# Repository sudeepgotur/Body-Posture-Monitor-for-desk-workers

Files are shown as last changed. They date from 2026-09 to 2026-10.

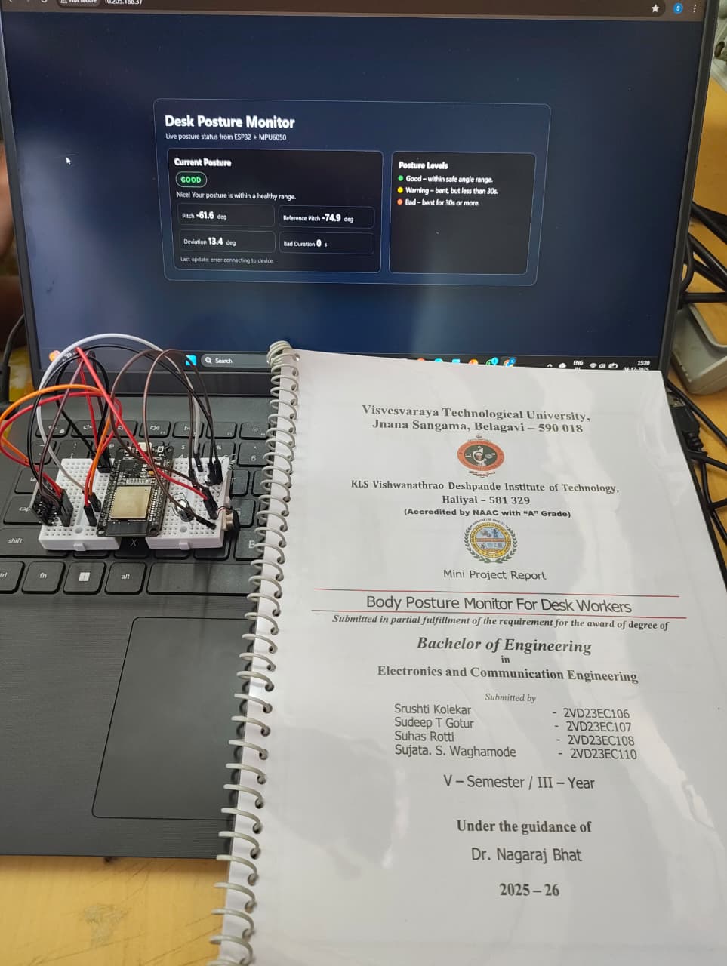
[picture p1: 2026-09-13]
images/final_setup_and_prototype/final_setup.jpeg

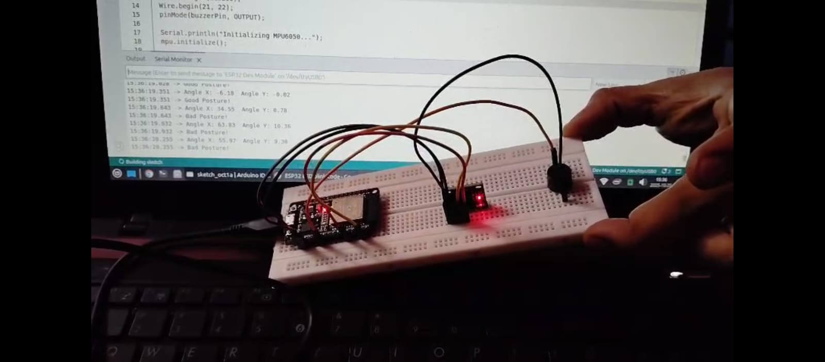
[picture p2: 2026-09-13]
images/final_setup_and_prototype/prototype.jpeg

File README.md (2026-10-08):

# Body Posture Monitor for Desk Workers

An ESP32-based embedded system for real-time posture monitoring and
prolonged bad-posture detection using an MPU6050 IMU sensor, with
vibration-based feedback and an integrated web-based monitoring
interface.

---

## 📌 Overview

The **Body Posture Monitor for Desk Workers** is an embedded system
developed to monitor a user's sitting posture in real time and provide
tactile feedback when an incorrect posture is maintained for a prolonged
period.

The system uses an **MPU6050 inertial measurement unit (IMU)** to obtain
body-orientation information. An **ESP32 microcontroller** processes the
sensor data, performs an initial posture calibration, calculates the
current pitch angle, and compares it with the calibrated reference
posture.

To prevent unnecessary alerts caused by short-term movements, the system
uses a **40-second bad-posture confirmation delay**. If the measured
posture remains outside the allowed range for the complete delay period,
the ESP32 activates a vibration motor to remind the user to correct their
posture.

The ESP32 also hosts a **web server** using its internal Wi-Fi
connectivity. The web interface is stored in the ESP32's **LittleFS
filesystem** and provides real-time posture information through a JSON
API.

A custom PCB was also designed as part of the hardware implementation.

---

## ✨ Features

- Real-time posture monitoring
- MPU6050-based posture sensing
- ESP32-based embedded processing
- Automatic 5-second posture calibration
- Reference posture angle generation
- Pitch-angle calculation
- 15° posture deviation tolerance
- Prolonged bad-posture detection
- 40-second confirmation delay
- Three posture states:
  - `GOOD`
  - `POTENTIALLY_BAD`
  - `BAD`
- Vibration-based tactile feedback
- 3-second vibration alert
- ESP32 Wi-Fi connectivity
- ESP32-hosted asynchronous web server
- LittleFS-based web interface
- Real-time JSON posture API
- Custom PCB design
- Low-cost embedded implementation
- Camera-free posture monitoring

---

# 🏗️ System Architecture

```text
                    ┌─────────────────────┐
                    │       MPU6050       │
                    │     IMU Sensor      │
                    │  Accelerometer/Gyro │
                    └──────────┬──────────┘
                               │
                           I²C / SDA-SCL
                               │
                               ▼
                    ┌─────────────────────┐
                    │        ESP32        │
                    │   Microcontroller   │
                    └──────────┬──────────┘
                               │
                 ┌─────────────┼─────────────┐
                 │             │             │
                 ▼             ▼             ▼
          Posture Logic    Vibrator      Wi-Fi
                 │          Control         │
                 │             │             │
                 ▼             ▼             ▼
          GOOD / BAD      Vibration     Web Server
          Detection          Alert           │
                                             ▼
                                       ┌─────────────┐
                                       │   LittleFS  │
                                       │             │
                                       │ index.html  │
                                       │ script.js   │
                                       │ style.css   │
                                       └──────┬──────┘
                                              │
                                              ▼
                                      Web Monitoring UI
```
---
## ⚙️ Working Principle

The system operates through the following sequence.

### 1. Initialization

When the ESP32 starts, it initializes:
- Serial communication
- I²C communication
- MPU6050
- Vibration motor control GPIO
- LittleFS
- Wi-Fi
- Asynchronous web server
The MPU6050 is connected to the ESP32 using the I²C interface.

### 2. Automatic Posture Calibration

After initialization, the system performs an automatic calibration.
The user is expected to sit in a normal posture for approximately
5 seconds.

During this period, the ESP32 continuously reads the MPU6050 pitch
values and calculates their average.
The resulting average is stored as the reference posture:

```text
              Normal Posture
                    │
                    ▼
             5-second calibration
                    │
                    ▼
              Read pitch values
                    │
                    ▼
              Calculate average
                    │
                    ▼
                 refPitch
```

This reference value is then used for subsequent posture monitoring.

### 3. Pitch Calculation

The ESP32 reads the raw accelerometer values from the MPU6050.

The accelerometer readings are converted into acceleration values and
used to calculate the pitch angle.

The implemented calculation is based on:

`pitch = atan2(Ay, √(Ax² + Az²))`

The resulting angle is expressed in degrees.

### 4. Posture Deviation

After calibration, the current pitch is compared with the calibrated
reference pitch.

The firmware calculates:

`deviation = pitch - refPitch`

The absolute deviation is then compared with the configured posture
tolerance.

The current firmware uses:

`PITCH_TOLERANCE = 15°`

Therefore:

```text
Absolute deviation ≤ 15°
        ↓
     GOOD

Absolute deviation > 15°
        ↓
Potentially incorrect posture
```
---

## 🚦 Posture States

The firmware provides three posture states.

| State | Description |
|---|---|
| `GOOD` | Posture is within the allowed deviation |
| `POTENTIALLY_BAD` | Posture has exceeded the allowed deviation, but the confirmation delay has not expired |
| `BAD` | Incorrect posture has remained beyond the 40-second confirmation period |

The state is provided to the web interface through the `/posture`
endpoint.

---

## ⏱️ Bad-Posture Confirmation

The system does not immediately activate the vibrator when the user's
posture becomes incorrect.

Instead, a timer is started.

```text
                Posture Reading
                      │
                      ▼
              Calculate Deviation
                      │
                      ▼
               Deviation > 15°?
                  │          │
                 NO         YES
                  │          │
                  ▼          ▼
                GOOD    Start Timer
                            │
                            ▼
                      Continue Monitoring
                            │
                            ▼
                      40 Seconds Reached?
                        │            │
                       NO           YES
                        │            │
                        ▼            ▼
               POTENTIALLY_BAD      BAD
                                    │
                                    ▼
                               Vibrator ON
```

If the user returns to the acceptable posture before the 40-second
period expires, the timer is reset.

If the incorrect posture continues for the complete 40 seconds, the
firmware confirms the posture as BAD.

---
                   
## 📳 Vibration Alert

The vibration motor is controlled through a transistor driver connected
to the ESP32.

When bad posture is confirmed:

```text
BAD posture confirmed
        │
        ▼
Vibrator activated
        │
        ▼
Approximately 3 seconds
        │
        ▼
Vibrator switched OFF
```

The current firmware uses a vibration duration of:

`BUZZ_DURATION = 3000 ms`

The vibration provides tactile feedback without requiring a visual or
audible alarm.

---

## 🌐 ESP32 Web Server

One of the important features of this project is that the ESP32
itself acts as the web server.

The firmware uses:

- ESPAsyncWebServer
- AsyncTCP
- WiFi
- ArduinoJson
- LittleFS

The ESP32 connects to a Wi-Fi network and starts an asynchronous web
server on port 80.

The web interface is stored in the ESP32's internal LittleFS
filesystem.

```text
ESP32
 │
 ├── Wi-Fi
 │
 ├── Async Web Server
 │
 └── LittleFS
      │
      ├── index.html
      ├── script.js
      └── style.css
```

---

## 📡 Posture JSON API

The firmware provides a dedicated endpoint:

`/posture`

This endpoint returns posture information in JSON format.

```text
Example structure:
{
    "pitch": 12.5,
    "refPitch": 10.2,
    "deviation": 2.3,
    "badSeconds": 0,
    "status": "GOOD"
}
```

The API provides:

- Current pitch
- Reference pitch
- Pitch deviation
- Duration of the current bad-posture condition
- Current posture status

The web interface can use this information to display the current
posture state and sensor values.

---

## 💾 LittleFS

The project uses LittleFS on the ESP32 to store and serve the web
interface files.

The firmware mounts LittleFS during startup:

```text
LittleFS
   │
   ├── index.html
   ├── script.js
   └── style.css
```

The ESP32 serves these files directly through its web server.

This allows the project to operate as a self-contained embedded web
application without requiring a separate computer or backend server for
the interface.

---

## 💻 Web Interface

The frontend of the project is organized as:

```text
software/
├── index.html
├── script.js
└── style.css
```

### index.html

Defines the structure of the web interface.

### script.js

Handles client-side interaction and communication with the ESP32 posture API.

### style.css

Provides the visual styling of the web interface.

Dashboard screenshots are available in:

```text
images/dashboard/
```

---

## 🔧 Hardware Components

| Component | Purpose |
|---|---|
| **ESP32** | Main microcontroller and processing unit |
| **MPU6050** | Accelerometer and gyroscope for posture sensing |
| **Vibration Motor** | Provides tactile feedback |
| **BC547 Transistor** | Drives the vibration motor |
| **Diode** | Protects the circuit from motor back-EMF |
| **Resistor** | Used in the transistor interface |
| **Capacitor** | Helps reduce power fluctuations and electrical noise |
| **USB Cable** | Programming and power |
| **Custom PCB** | Hardware integration |

---

## 🧩 MPU6050

The MPU6050 is a 6-axis inertial measurement unit containing:

- 3-axis accelerometer
- 3-axis gyroscope

In this project, the sensor is used to obtain body-orientation
information for posture monitoring.

The sensor communicates with the ESP32 using:
I²C

The ESP32 uses the sensor readings to calculate the user's pitch angle
and determine posture deviation from the calibrated reference.

---

## 🔌 Circuit and Vibration Driver

The vibration motor is not driven directly from the ESP32 GPIO.
Instead, a transistor driver stage is used.

```text
             ESP32 GPIO
                  │
                  ▼
             Base Resistor
                  │
                  ▼
              BC547 NPN
                  │
                  ▼
           Vibration Motor
                  │
                  ▼
               GND

```

A protection diode is included to reduce the effects of the motor's
back-EMF.

The circuit diagram is available at:
hardware/circuit_diagram/circuit_diagram.jpeg

---

## 🖥️ Firmware

The main ESP32 firmware is located at:

```text
firmware/
└── ESP_code_for_monitor.ino
```

The firmware handles:

- MPU6050 initialization
- I²C communication
- 5-second calibration
- Pitch calculation
- Posture deviation calculation
- 15° tolerance comparison
- 40-second bad-posture confirmation
- Vibration control
- Wi-Fi connection
- LittleFS
- Web server
- JSON API
- Serial debugging

---

## 🔌 PCB Design

A custom PCB was designed as part of the project to integrate the
required hardware circuitry.

The PCB resources are organized as:

```text
hardware/
└── pcb/
    ├── BOM/
    ├── Final_PCB/
    ├── Gerber_Posture-Monitor-PCB-1_PCB_Posture-Monitor-PCB-1_2026-10-07/
    └── Schematic/
```

Included PCB Resources

- Bill of Materials
- Schematic
- Final PCB design
- Gerber manufacturing files

The PCB files document the hardware design and manufacturing workflow
of the project.

---

## 📷 Project Images

**Final Setup and Prototype**
Images of the physical implementation are available in:

`images/final_setup_and_prototype/`

Contents include:

- Final setup
- Hardware prototype
- Project implementation photographs

**Web Dashboard**
Screenshots of the monitoring interface are available in:

`images/dashboard/`

---

## 📊 Posture Detection Logic

The overall detection process can be summarized as:

```text
                  Start
                    │
                    ▼
              Initialize ESP32
                    │
                    ▼
              Initialize MPU6050
                    │
                    ▼
            5-second Calibration
                    │
                    ▼
              Store refPitch
                    │
                    ▼
              Read MPU6050
                    │
                    ▼
             Calculate Pitch
                    │
                    ▼
          Calculate Deviation
                    │
                    ▼
           Deviation > 15°?
              │           │
             NO          YES
              │           │
              ▼           ▼
            GOOD    POTENTIALLY_BAD
                          │
                          ▼
                      Start Timer
                          │
                          ▼
                    40 Seconds?
                     │        │
                    NO       YES
                     │        │
                     ▼        ▼
                 Continue     BAD
                              │
                              ▼
                         Vibrator ON
                              │
                              ▼
                          ~3 Seconds
                              │
                              ▼
                         Vibrator OFF
                              │
                              ▼
                       Continue Monitoring

```

---

## 🎯 Objectives

The project was developed with the following objectives:

- Design a posture monitoring system for desk workers.
- Measure body orientation using an MPU6050.
- Process sensor data using an ESP32.
- Detect incorrect posture.
- Provide vibration-based feedback.
- Reduce unnecessary alerts caused by temporary movements.
- Implement a delayed alert mechanism.
- Improve awareness of proper sitting posture.

---

## 📈 Project Outcomes

The implemented system demonstrates:

- Real-time posture monitoring.
- MPU6050-based angle measurement.
- Automatic posture calibration.
- Reference-based posture deviation detection.
- 15° posture tolerance.
- 40-second delayed bad-posture confirmation.
- Vibration-based tactile feedback.
- ESP32 Wi-Fi connectivity.
- Embedded web-server functionality.
- LittleFS-based web interface.
- Real-time posture data through a JSON endpoint.
- Custom PCB implementation.

---

## 🛠️ Technologies Used

Hardware

- ESP32
- MPU6050
- Vibration Motor
- BC547 Transistor
- Diode
- Resistors
- Capacitor
- Custom PCB
Embedded Software
- Arduino IDE
- Arduino C/C++
- ESP32 Board Package
- Wire.h
- WiFi.h
- ESPAsyncWebServer
- AsyncTCP
- ArduinoJson
- LittleFS
Communication
- I²C
- Wi-Fi
- HTTP
- JSON
Frontend
- HTML
- CSS
- JavaScript

---

## 📁 Repository Structure

```text
Body-Posture-Monitor-Desk-Workers/
│
├── README.md
├── LICENSE
├── .gitignore
│
├── docs/
│
├── firmware/
│   └── ESP_code_for_monitor.ino
│
├── hardware/
│   ├── circuit_diagram/
│   │   └── circuit_diagram.jpeg
│   │
│   └── pcb/
│       ├── BOM/
│       ├── Final_PCB/
│       ├── Gerber_Posture-Monitor-PCB-1_PCB_Posture-Monitor-PCB-1_2026-10-07/
│       └── Schematic/
│
├── images/
│   ├── dashboard/
│   │   ├── Posture_image1.jpeg
│   │   ├── Posture_image2.jpeg
│   │   ├── Posture_image3.jpeg
│   │   └── Posture_image4.jpeg
│   │
│   └── final_setup_and_prototype/
│       ├── final_setup.jpeg
│       ├── final_setup2.jpeg
│       └── prototype.jpeg
│
└── software/
    ├── index.html
    ├── script.js
    └── style.css

```

---

# 📚 Documentation

The `docs/` directory contains the project's detailed documentation
and presentation materials.

### Project Report

The complete project report contains detailed information about the
project, including the problem statement, objectives, methodology,
hardware and software implementation, results, and project outcomes.

### Project Presentation

The project presentation provides a concise overview of the system,
its architecture, implementation, and results.

```text
docs/
├── Body Posture Monitor For Desk Workers (4) [1].pptx
└── Project_report_final(BPM)[1](AutoRecovered)[1].pdf
```

---

## 🏫 Project Information

**Project Title**: Body Posture Monitor for Desk Workers
**Project Type**: Mini Project
**Department**: Electronics and Communication Engineering
**Institution**: KLS Vishwanrao Deshpande Institute of Technology, Haliyal
**University**: Visvesvaraya Technological University (VTU)
**Academic Year**: 2025–2026
**Guide**: Dr. Nagaraj Bhat

---

## 👥 Team Members

- **Srushti Kolekar** — 2VD23EC106
- **Sudeep T. Gotur** — 2VD23EC107
- **Suhas Rotti** — 2VD23EC108
- **Sujata S. Waghamode** — 2VD23EC110

---

## 👨‍💻 My Contribution

My primary contribution to the project focused on the hardware and
embedded-system implementation.

Hardware
- ESP32 and MPU6050 interfacing
- Sensor integration
- Circuit implementation
- Hardware assembly
- Testing and debugging
- Completed the PCB development

Embedded System
- ESP32 firmware development
- MPU6050 sensor data acquisition
- Posture calibration
- Posture-angle calculation
- Posture detection logic
- Bad-posture timing mechanism
- Vibration-alert control

Web Interface
- LittleFS integration
- Posture JSON API
- Integration of the embedded system with the web interface

---

## 📜 License

This project is released under the MIT License.
See the LICENSE file for details.

---

## 👤 Author

Sudeep T. Gotur
Bachelor of Engineering
Electronics and Communication Engineering
KLS Vishwanrao Deshpande Institute of Technology, Haliyal

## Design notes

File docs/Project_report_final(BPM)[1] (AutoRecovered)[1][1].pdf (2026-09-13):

Visvesvaraya Technological University,

# Jnana Sangama, Belagavi – 590 018

## Under the guidance of

## Dr. Nagaraj Bhat

2025 – 26

KLS Vishwanathrao Deshpande Institute of Technology,

## Haliyal – 581 329

(Accredited by NAAC with “A” Grade)

## Mini Project Report

# Body Posture Monitor For Desk Workers

Submitted in partial fulfillment of the requirement for the award of degree of

# Bachelor of Engineering

in

## Electronics and Communication Engineering

Submitted by
Srushti Kolekar | - 2VD23EC106
Sudeep T Gotur | - 2VD23EC107
Suhas Rotti | - 2VD23EC108
Sujata. S. Waghamode | - 2VD23EC110

## V – Semester / III – Year

Visvesvaraya Technological University,

# Jnana Sangama, Belagavi – 590 018

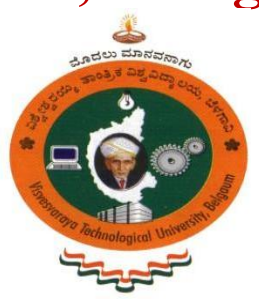
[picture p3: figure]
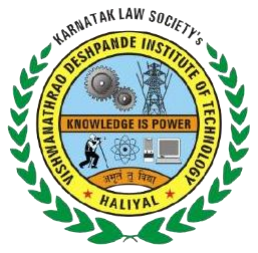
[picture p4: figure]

### Under the guidance of

## Dr. Nagaraj Bhat

2025 – 26

KLS Vishwanathrao Deshpande Institute of Technology,

## Haliyal – 581 329

(Accredited by NAAC with “A” Grade)

## Department of Electronics and Communication Engineering

## Mini Project Report

# Body Posture Monitor For Desk workers

Submitted by
Srushti Kolekar | - 2VD23EC106
Sudeep T Gotur | - 2VD23EC107
Suhas Rotti | - 2VD23EC108
Sujata S. Waghamode | - 2VD23EC110

## V – Semester / III – Year

Visvesvaraya Technological University,

## Jnana Sangama, Belagavi – 590 018

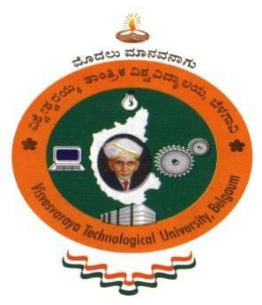
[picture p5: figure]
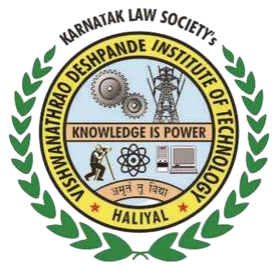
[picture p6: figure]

KLS Vishwanathrao Deshpande Institute of Technology,

## Haliyal – 581 329

(Accredited by NAAC with “A” Grade)

## Department of Electronics and Communication Engineering

## CERTIFICATE

Certified that the Mini Project Work entitled “ Body Posture Monitor for Desk Workes” carried out by

Srushti Kolekar | - 2VD23EC106
Sudeep T Gotur | - 2VD23EC107
Suhas Rotti | - 2VD23EC108

Sujata S. Waghamode - 2VD23EC110

are Bonafide Students of KLS VDIT, Haliyal, in partial fulfillment for the award of Bachelor of Engineering in Electronics and Communication Engineering, of the Visvesvaraya Technological University, Belagavi during the Year 2025-2026. It is certified that all corrections / suggestions indicated for Internal Assessment have been incorporated in the Report deposited in the Departmental Library. The Mini Project report has been approved as it satisfies the academic requirements in respect of Mini Project Work prescribed for the said Degree.

GUIDE
(Dr. Nagaraj Bhat)

HOD
(Dr. Nagaraj Bhat)

PRINCIPAL
(Dr. V. A. Kulkarni)
Name of the Examiners | Signature with Date

1.

2.

============================================================================================== ================================================================

Body Posture monitor For Desk Workers
============================================================================

=============================================================================

## TABLE OF CONTENTS

Sl. No | Contents | Page No.
1 | Introduction | 1
2 | Literature Survey | 2
3 | Methodology | 4
4 | Outcomes | 10
5 | Advantages | 13
6 | Applications | 15
7 | Conclusion | 16
8 | References | 17

## LIST OF FIGURES

Sl. No | List of Figures | Page No.
1 | Block Diagram of Posture Corrector | 6
2 | Flowchart Of Posture Correction System | 8
3 | Posture is Good | 12
4 | Posture Warning | 12
5 | Posture is Bad | 12

Dept. of E&C, KLS VDIT, Haliyal | 1
Page No.

## CHAPTER 1:

## INTRODUCTION

## 1.1 Introduction

In today’s digital era, many people spend long hours sitting at desks, often in front of computers. Poor

sitting or standing posture over prolonged periods can lead to back pain, spinal misalignment, and other

health issues. Maintaining correct posture is essential for the overall health and productivity of desk

workers, students, and professionals. With the advancement of sensor-based technology and affordable

microcontrollers, it is now possible to develop compact devices that can monitor posture and alert users in

real time.

## 1.2 Motivation

Observations show that most individuals working for extended hours at desks are unaware of their body

posture. Continuous bending or slouching causes strain on the neck and spine. This motivated the

development of a small, wearable, and cost-effective device that can detect improper posture and remind

users to correct it, thereby improving health and comfort

## 1.3 Objectives

1.To design a wearable system for detecting incorrect sitting posture.

2.To Interface Flex sensor with ESP32 using MPU6050 for quaternion-based tracking.

3.To generate alerts using vibration motor when posture deviates beyond threshold.

4.To ensure portability by integrating the system into a light weight jacket.

5.To promote better erogonomics for desk workers and reduce health risks.

## 1.4 Scope of the Project

The proposed system is a portable, low-cost posture monitoring device using an ESP32 microcontroller

and an MPU6050 sensor. It can be used by anyone who spends long hours sitting or standing in a fixed

position. The project also provides a base for future enhancement, such as adding IoT features for mobile

notifications, data logging, and posture-tracking analytics.

## CHAPTER 2:

## LITERATURE SURVEY

1. UWB-Posture Guard: A Privacy-Preserving RF Sensing System for Continuous Ergonomic Sitting

Posture Monitoring

Authors: Haotang Li et all

Explanation:

- Contactless Monitoring: Uses ultra-wideband (UWB) RF signals to sense posture without cameras

or wearables, ensuring strong privacy.

- Temporal Classification: Introduces a gradient-boosted decision-tree model (PoseGBDT) for

analyzing continuous posture sequences.

- High Accuracy: Achieves ~99% accuracy across 19 sitting postures, robust against clothing,

devices, and environmental changes.

- Real-World Usability: Designed for continuous, long-term ergonomic monitoring in offices while

minimizing invasiveness.

### 2. Sitting Posture Recognition and Feedback: A Literature Review

Authors: Christian Krauter et al.

Explanation:

- Comprehensive Survey: Reviews 223 papers related to sitting posture detection and feedback

mechanisms.

- Common Technologies: Finds that pressure sensors and visual feedback systems are the dominant

sensing and feedback methods.

- Design Trade-offs Identified: Highlights challenges such as privacy, accuracy, cost, and user comfort

across different approaches.

- Gap in Long-Term Studies: Notes lack of consistent evaluation methods and calls for long-term, real-

world posture studies.

### 3. Sensor-Based Wearable Systems for Monitoring Human Motion and Posture: A Review

Authors: Xinxin Huang et al.

Explanation:

- Wearable Focus: Provides a wide review of wearable sensors (IMUs, accelerometers, gyros, flexible

sensors) used for motion/posture monitoring.

- Sensor Placement Analysis: Discusses optimal placement (waist, trunk, limbs) and how placement

affects accuracy and comfort.

- System Design Discussion: Covers complete pipeline: sensing, transmission, processing, and real-time

monitoring challenges.

- Future Challenges: Identifies accuracy, durability of flexible sensors, and data privacy as critical areas

for improvement.

4. A Smart System for Sitting Posture Detection Based on Force Sensors and Mobile Application

Authors: Slavomir Matuska et al.

Explanation:

- Pressure-Based System: Uses 6 force sensors embedded in a chair to detect multiple sitting postures.
- IoT Architecture: Employs Arduino/NodeMCU to collect data and send posture information to a

mobile app.

- Real-Time Feedback: Mobile app provides posture warnings and tracks long-term sitting behavior.
- Practical Implementation: Designed for office use and demonstrates a low-cost, deployable smart-chair

solution.

### 5. Human Posture Detection Method Based on Wearable Devices

Authors: Xiaoou Li, Yangang Li, Yuanming Wu, Jiahui Xu, Zhitao Xiao

Explanation:

- Multi-Sensor Fusion: Combines upper-limb sEMG, triaxial acceleration, and plantar pressure

sensors for posture and gait recognition.

- Feature Engineering: Extracts statistical and wavelet features from EMG and IMU data for robust

classification.

- Machine Learning: Uses a GA-optimized SVM classifier to improve detection accuracy.
- Strong Performance: Achieves ~90% accuracy for both virtual motion control and gait recogniti

## CHAPTER 3:

## METHODOLOGY

This chapter explains the overall design, components used, system architecture, and working principle of

the Body Posture Monitoring System for Desk Workers. The system combines sensor-based angle

detection, microcontroller processing, and delayed feedback to help users maintain proper sitting posture.

## 3.1 Overview

The proposed system is designed to continuously monitor the posture of a desk worker using an MPU6050

accelerometer-gyroscope sensor. The sensor measures the tilt angle of the upper body. The ESP32

microcontroller processes these readings and compares them with a calibrated baseline posture. If a user

bends or leans forward beyond a certain angle and maintains this incorrect posture for more than 40 seconds,

the system activates a vibrater to alert the user.

The system is:

- Low cost
- Non-intrusive (no camera, no wearable)
- Simple to use
- Real-time
- Highly suitable for desk workers and students

To prevent false alerts when the user bends briefly to pick up an object or reach for something, a time delay

mechanism is added.

## 3.2 Hardware Components Used

- ESP32 Microcontroller

Acts as the main controller.

Performs sensor reading, data processing, and vibration control.

- MPU6050 (Accelerometer + Gyroscope)

Mounted on the upper limb/back.

Measures body tilt to identify slouching or leaning forward.

- Flex Sensor

Placed on the lower limb.

Detects bending of the knee or excessive forward leaning.

- Vibration Motor (Coin Type)

Provides haptic feedback when the posture is incorrect for a prolonged period.

- BEC548 Transistor

Used as a driver to control the vibration motor safely.

- 1N4148 / 1N4007 Diode

Protects the circuit from motor back-EMF.

- 100 µF Capacitor

Smoothens motor power fluctuations and reduces electrical noise.

- Resistors

1 kΩ for transistor base.

## 3.3 Software Components Used

1. Arduino IDE
- Used for writing, compiling, and uploading the ESP32 program
2. ESP32 Board Package
- Required to program ESP32 in Arduino IDE
- Provides GPIO definitions and bootloader support
3. Wire.h Library
- Enables I2C communication between ESP32 and MPU6050
4. Core Embedded C/C++ Code
- Implements:
- Sensor calibration
- Complementary filtering
- Angle computation

## 3.4 Block diagram

The block diagram represents the overall functioning of the “Body Posture for Desk Workers” system. The

MPU6050 and flex sensor act as the primary input units that continuously monitor the user’s upper-body

tilt and lower-limb bending. These sensors send real-time analog and digital data to the ESP32

microcontroller, which serves as the central processing unit of the system. Inside the ESP32, the posture

data is filtered, processed, and compared with predefined thresholds to determine whether the user is

maintaining a correct or incorrect sitting posture. A timing logic is also implemented so that incorrect

posture must be sustained for more than 40 seconds before triggering feedback. Once the ESP32 detects

prolonged bad posture, it activates the vibration motor through a transistor driver circuit. This haptic

feedback alerts the user to correct their posture, making the system an effective and non-intrusive posture

correction tool.

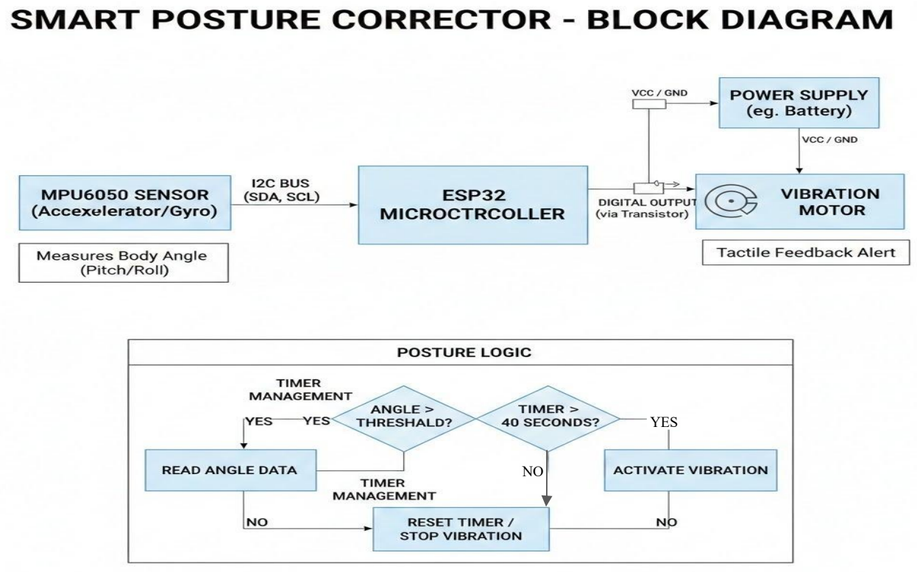
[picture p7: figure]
YES

Fig: 3.1 Block Diagram of Posture Corrector

## 3.5 Flowchart

The flowchart describes the step-by-step operational logic of the posture monitoring system. It outlines

how the system reads sensor data, processes posture, and triggers an alert only when necessary.

1. Start System

The ESP32 initializes all hardware components, including I2C communication and the MPU6050

sensor.

The system also performs a calibration phase where the baseline posture angle is recorded.

2. Read MPU6050 Values

The ESP32 continuously reads accelerometer and gyroscope data from the MPU6050. These raw values

represent the user’s real-time movement and orientation.

3. Calculate Angle

Using the complementary filter technique, the ESP32 calculates a stable pitch angle of the user’s upper

body. This angle indicates how far the user is leaning forward or backward.

4. Compare Angle with Baseline

The calculated angle is compared with the calibrated baseline angle.

- If the angle difference is below the threshold, the posture is considered correct.
- If it exceeds the threshold, the posture is considered bad.
5. Posture OK (Good Posture Path)

If the posture is correct:

- The system resets the timer.
- The vibrator remains OFF.
- The system continues monitoring without any interruption

6.Bad Posture Detected (Angle > Threshold)

When the system detects bad posture:

- It does NOT activate the vibrator immediately.
- Instead, it starts or continues a timer to track how long the user remains in bad posture.

7.Check Timer (40 Seconds)

If the user stays in incorrect posture for less than 40 seconds

- No vibrator is activated.
- This prevents false alerts caused by temporary actions like picking up a pen or leaning briefly.

If the timer reaches or exceeds 40 seconds, the system proceeds to the next step.

8.Turn Vibrator ON

If bad posture persists beyond 40 seconds, the ESP32 activates the vibrator to alert the user.

The vibrator remains ON until the user corrects their posture and the angle returns within the threshold

limits.

9.Continuous Monitoring

The system loops back to continuously read data and analyze posture, ensuring real-time monitoring

throughout the user’s sitting period.

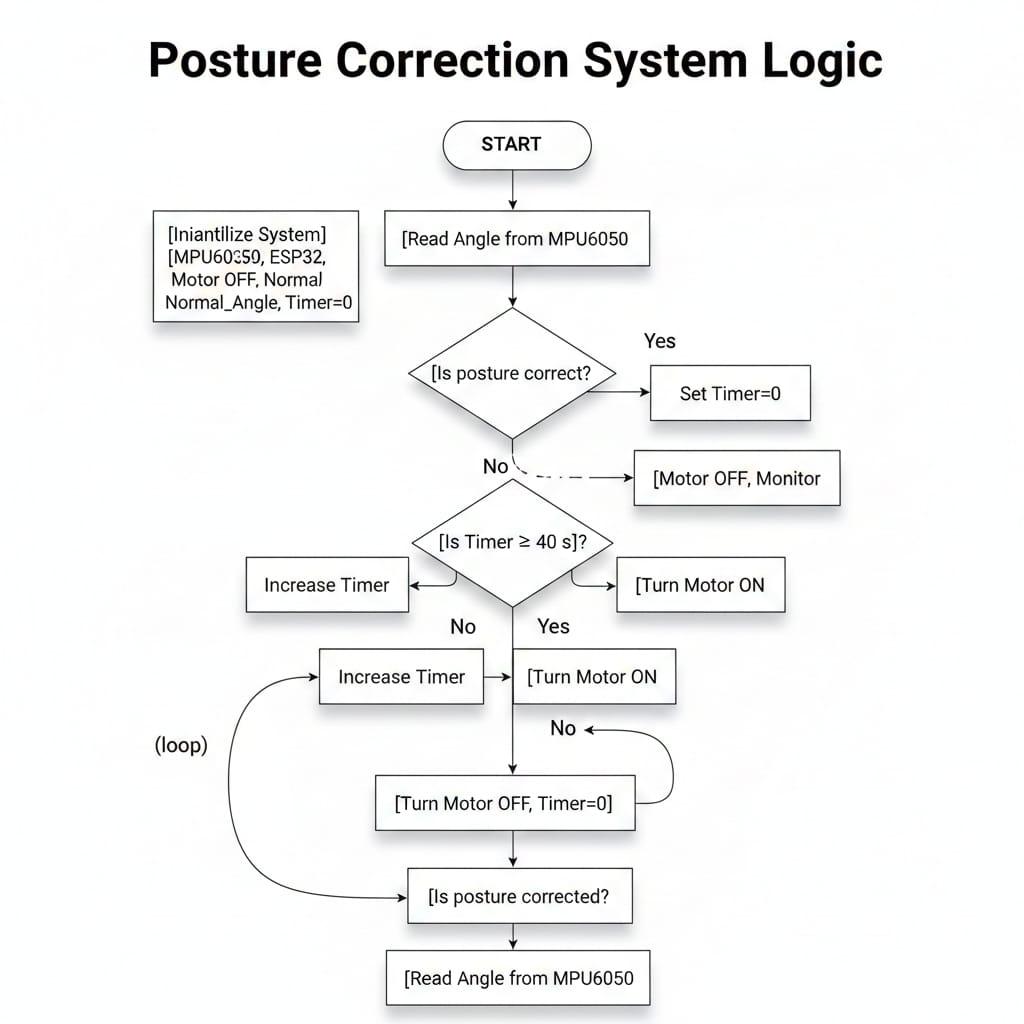
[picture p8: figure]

Fig:3.2 Flowchart of Posture Correction System

## 3.6 Working of system

Step 1: Initialization
- ESP32 boots and initializes I2C communication.
- MPU6050 is calibrated for 5 seconds while the user sits in a normal posture.
- The baseline pitch angle is stored.
Step 2: Reading Sensor Data
- MPU6050 sends accelerometer and gyroscope values continuously.
- ESP32 reads this data at regular intervals.
Step 3: Angle Calculation
- Using both accelerometer and gyroscope, a complementary filter computes a stable pitch angle.
- This angle represents the user’s upper-body tilt.
Step 4: Posture Classification
- ESP32 compares the real-time angle with the baseline angle.
- If the angle difference is within the threshold, posture is considered normal.
Step 5: Delay Logic for False-Alert Prevention
- If bad posture is detected, a timer starts.
- If user corrects posture before 40 seconds, the timer resets (no vibration).
Step 6: Vibrator Alert
- If bad posture continues beyond 40 seconds, ESP32 activates the vibrator.
- The vibrator remains ON until the user returns to a normal posture.
Step 7: Continuous Monitoring
- The system runs 24/7 as long as it is powered.
- Helps users maintain correct posture through immediate feedback.

## CHAPTER 4:

## OUTCOME

The Body Posture Monitoring System for Desk Workers is designed to detect incorrect sitting posture and

provide timely feedback to the user. After implementation and testing, the following outcomes were

achieved:

- Accurate Posture Angle Measurement

The system should correctly detect upper-body tilt using the MPU6050 sensor and measure the posture

angle in real time.

- Reliable Bad Posture Detection

The system is expected to classify posture as “good” or “bad” based on a predefined angle threshold.

- Delay-Based Alert Mechanism

The system should only trigger an alert if the user maintains incorrect posture continuously for more

than 40 seconds.

- Instant User Feedback

When prolonged bad posture is detected, the vibrator should activate immediately to alert the

user.

- User-Friendly Operation

The system should run automatically without requiring complex setup, calibration, or wearable

devices.

## 4.2 Achieved Outcomes

1. Stable and Real-Time Angle Monitoring

The MPU6050 successfully captured continuous accelerometer and gyroscope readings.

The complementary filter produced stable pitch-angle values with minimal noise.

2. Correct Posture Classification

The system correctly identified good posture when the angle difference remained below the set

threshold (e.g., 25°).

Incorrect posture was detected consistently when the user leaned forward beyond the threshold.

3. Accurate 40-Second Delay Implementation

The timer logic worked as intended:

a. No vibrator during short accidental movements.
b. Alert triggered only when the user stayed in bad posture for ≥ 40 seconds.
4. Effective vibrator Feedback

The vibrator activated immediately after the delay time was crossed.

It switched OFF as soon as the user corrected their posture.

5. Simple, Low-Cost, and Non-Intrusive System

The whole system worked without wearables, cameras, or bulky hardware.

It required only ESP32, MPU6050, and a vibrator.

## 4.3 Measurable System Performance

### 1. Angle Detection Accuracy

- The MPU6050 provided consistent angle readings with good stability.
- The complementary filter ensured smooth and accurate posture angle calculation.

### 2. False Alarm Prevention

- Short-duration bending (< 40 seconds) did not trigger the vibrator.
- This confirms the delay mechanism works effectively.

### 3. Responsiveness

- vibrator activation occurred within 1–2 seconds after the 40-second timer completed.
- System responded instantly when posture was corrected.

### 4. Continuous Operation

- The system remained stable during long monitoring sessions (1–2 hours).

## 4.4 Benefits of the Developed System

1. Improves Ergonomic Awareness

Users become conscious of their sitting posture during work or study.

2. Reduces Risk of Back and Neck Pain

Immediate feedback helps prevent prolonged slouching, protecting spinal health.

3. Low-Cost and Easily Reproducible

Uses inexpensive components suitable for student and office applications.

4. Non-Intrusive and Privacy-Friendly

No camera, no wearable devices, no personal data collection.

5. Suitable for Long-Duration Use

Ideal for desk workers, students, programmers, and office employees.

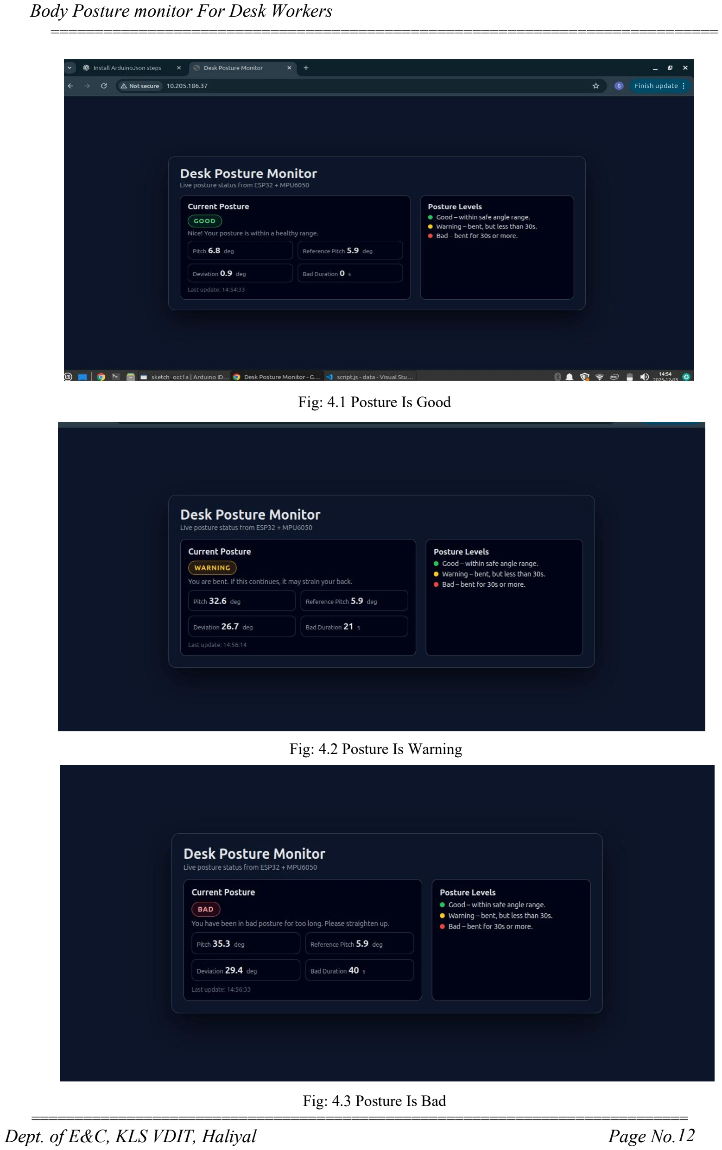
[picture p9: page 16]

Fig: 4.1 Posture Is Good

Fig: 4.2 Posture Is Warning

Fig: 4.3 Posture Is Bad

## CHAPTER 5:

## ADVANTAGES

The Body Posture Monitoring System for Desk Workers offers several practical and technical

advantages that make it an effective, reliable, and user-friendly solution for posture correction. The key

advantages are outlined below:

### 1. Low-Cost and Easily Implementable

The system uses inexpensive and readily available components such as the ESP32, MPU6050, and a

simple vibrator. This makes it affordable for students, offices, and personal use without requiring

specialized hardware or complex installations.

### 2. Real-Time and Continuous Monitoring

The posture of the user is monitored continuously in real time. This ensures that even small posture

deviations or prolonged slouching are detected immediately, allowing users to maintain correct posture

during extended working hours.

### 3. High Accuracy Using Sensor

The MPU6050 provides reliable accelerometer and gyroscope readings. Through complementary

filtering, the system achieves stable and accurate posture angle calculations, making detection precise

and trustworthy.

### 4. Prevents False Alerts

A major advantage of this system is its 40-second delay mechanism. The vibrator triggers only when

the user maintains a bad posture for an extended duration. This prevents unnecessary alerts when the

user bends temporarily to adjust their seating or pick something up.

### 5. Simple and User-Friendly Operation

The system requires no calibration beyond initial setup and does not demand any technical knowledge

from the user. Once powered ON, it works automatically in the background without disturbing normal

activities.

### 6. Privacy-Friendly Solution

Unlike camera-based posture monitoring systems, this design uses only motion data. It does not record

any video or image, making it completely privacy-safe for homes, offices, libraries, and shared

environments.

### 7. Non-Intrusive and Comfortable

The system does not require the user to wear any device or attach sensors to the body. It can be placed

on the desk or integrated into the chair, providing full comfort and ease of use.

### 8. Portable and Compact Design

Using compact components like ESP32 and MPU6050, the system is lightweight and portable. It can be

used across multiple locations such as study rooms, classrooms, and workplace cabins.

### 9. Promotes Healthy Sitting Habits

By providing timely alerts, the system helps users correct their posture regularly. Over time, this

encourages better spinal alignment, reduces back/neck pain, and improves long-term health.

### 10. Expandable and Upgradable

The system can be easily upgraded with additional features such as:

- Mobile notifications via Wi-Fi
- Data logging
- Habit tracking
- AI-based analytics

The ESP32’s capabilities make future enhancements simple to implement

## CHAPTER 6:

## APPLICATIONS

The Body Posture Monitoring System for Desk Workers can be applied in various environments where

people sit for long hours. Its simple design, low cost, and non-intrusive operation make it useful for

multiple practical applications.

### 1. Office Workspaces

Employees often spend long periods sitting at desks, leading to poor posture habits. This system can be

used in corporate offices to help workers maintain an ergonomic sitting posture and prevent back and neck

pain.

### 2. Home Study Rooms

Students studying at home frequently develop unhealthy posture while reading, writing, or using

computers. The device can assist in developing and maintaining correct sitting habits to avoid long-term

spinal issues.

### 3. Schools and Educational Institutions

Libraries, computer labs, and classrooms can benefit from this system. It helps students maintain posture

while performing academic tasks, improving concentration and long-term health.

### 4. IT Companies and Coding Environments

Programmers and developers typically sit for extended hours. This system provides constant posture

monitoring to prevent slouching, spinalstrain, and fatigue—common issues in the IT industry.

### 5. Co-Working Spaces

Shared office environments can adopt this device to promote user wellness and encourage good sitting

posture among individuals working independently.

### 6. Medical and Physiotherapy Centers

The system can assist physiotherapists in monitoring posture improvement in patients undergoing therapy

for back or neck pain. It can also be used in rehabilitation exercises where posture tracking is important.

### 7. Remote Work and Work-From-Home Setups

Many individuals working from home lack ergonomic furniture. This posture monitoring system helps

them maintain healthy posture during long work sessions in informal environments.

## CONCLUSION

The “Body Posture for Desk Workers” system successfully demonstrates a practical and effective solution for

monitoring and correcting poor sitting posture using low-cost hardware components. By integrating an

MPU6050 sensor on the upper limb and a flex sensor on the lower limb, the system is able to continuously

measure body tilt and bending angles with good accuracy. The ESP32 microcontroller plays a central role in

processing real-time sensor data, applying threshold conditions, and determining whether the user is sitting

correctly or not. The inclusion of a 40-second delay mechanism ensures that the system avoids false triggers

caused by short-term movements, such as reaching for objects or adjusting the seat position. This greatly

improves the reliability and usability of the design in real working environments.

The vibration motor provides a simple yet effective feedback method that immediately alerts the user to correct

their posture without disturbing others. Throughout testing, the system showed stable performance, quick

response, and minimal false positives, making it suitable for office workers, students, and individuals who spend

long hours at a desk. The project meets its primary objectives of creating a compact, affordable, and privacy-

preserving posture correction device. Overall, the system promotes healthier sitting habits, reduces the risk of

posture-related discomfort, and demonstrates how embedded systems can be applied to improve daily

ergonomic awareness.

In addition to achieving its technical objectives, this mini-project highlights the potential of combining simple

wearable sensors with intelligent decision logic to address real-world ergonomic problems. The system

demonstrates that posture monitoring does not require complex or expensive equipment; instead, effective

results can be achieved through thoughtful sensor placement, smart timing mechanisms, and user-friendly

feedback methods. The project also reinforces the growing importance of health-focused embedded systems,

especially for individuals who spend extended hours sitting for work or study. By encouraging better posture

habits through timely feedback, the system contributes to long-term health benefits and improved productivity.

This work can further serve as a foundation for developing more advanced posture monitoring solutions with

expanded sensing capabilities, data logging, analytics, or integration with mobile applications.

## REFERENCES

1. UWB-Posture Guard: A Privacy-Preserving RF Sensing System for Continuous Ergonomic Sitting

Posture Monitoring

Authors: Haotang Li, Zhenyu Qi, Sen He, Kebin Peng, Sheng Tan, Yili Ren, Tomas Cerny, Jiyue Zhao,

Zi Wang.(2025)

2. Sitting Posture Recognition and Feedback: A Literature Review

Authors: Christian Krauter, Katrin Angerbauer, Aimée Sousa Calepso, Alexander Achberger, Sven

Mayer, Michael Sedlmair.(2024)

3. Sensor-Based Wearable Systems for Monitoring Human Motion and Posture: A Review

Authors: Xinxin Huang, Yunan Xue, Shuyun Ren, Fei Wang. (2024)

4. A Smart System for Sitting Posture Detection Based on Force Sensors and Mobile Application

Authors: Slavomir Matuska, Martin Paralic, Robert Hudec. (2022)

5. Human Posture Detection Method Based on Wearable Devices

Authors: Xiaoou Li, Yangang Li, Yuanming Wu, Jiahui Xu, Zhitao Xiao (2021)

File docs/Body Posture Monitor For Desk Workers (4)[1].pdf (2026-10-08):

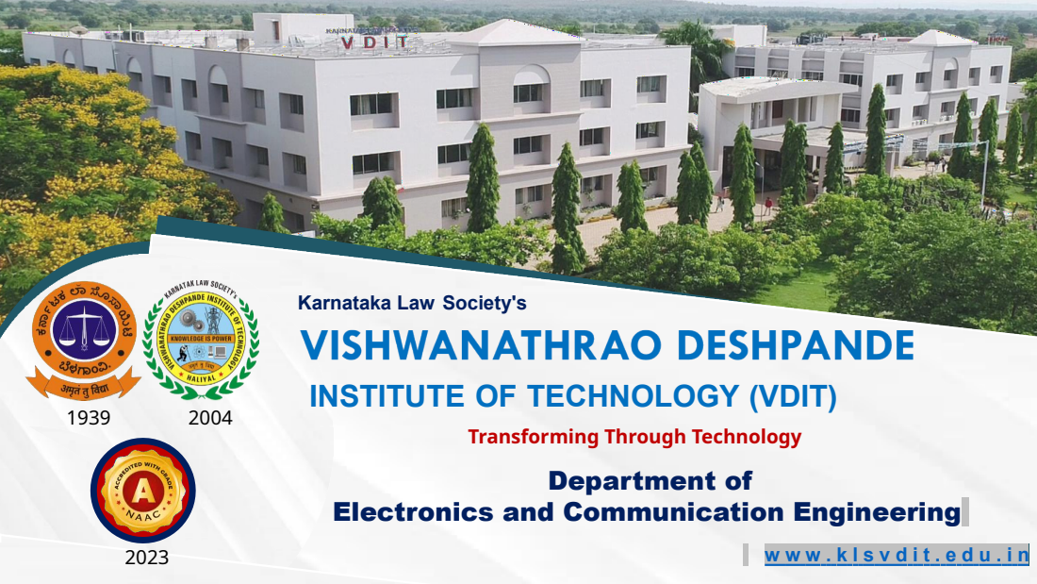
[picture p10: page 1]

Karnataka Law Society's

INSTITUTE OF TECHNOLOGY (VDIT)

Transforming Through Technology
Department of

Electronics and Communication Engineering

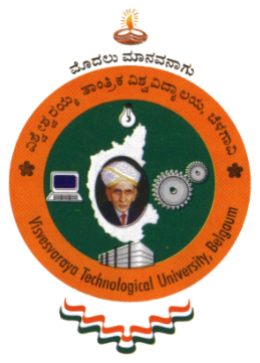
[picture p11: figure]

A Presentation entitled
Body Posture Monitor For Desk Workers

Presented by

Under the Guidance of

Dr. Nagaraj. Bhat

Department of E&CE

(Academic Year 2024-25)

Visvesvaraya Technological University, Jnana Sangama,

### Belagavi – 590 018

KLS Vishwanathrao Deshpande Institute of Technology,

## Haliyal – 581 329

(Accredited by NAAC with “A” Grade)

Srushti Kolekar | 2VD23EC106
Sudeep T. Gotur | 2VD23EC107
Suhas Rotti | 2VD23EC108
Sujata S. Waghamode | 2VD23EC110

09/10/2026 | 3

# PRESENTATION OUTLINE

Ø Motivation
Ø Introduction
Ø Literature Survey
Ø Objectives
Ø Block Diagram
Ø Circuit Diagram
Ø Working
Ø Outcomes
Ø Advantages
Ø Applications
Ø References
Ø Acknowledgement

Body Posture Monitor For Desk Workers

# MOTIVATION

ØMany desk workers suffer from back pain and neck pain

ØPeople unknowingly sit in the wrong posture for long hours

ØNo real-time alert system to correct posture

ØMedical treatment is costly and time-consuming

ØPrevention is better than a cure

ØSimple technology can improve daily life

ØOur goal is to use sensors to improve human health

ØThis project brings technology and health together

# INTRODUCTION

### ØBody posture is the position in which we sit or stand

### ØCorrect posture keeps the spine healthy

### ØDesk workers sit for long hours daily

### ØWrong sitting posture causes: ( Back pain, Neck pain, Shoulder strain)

### ØMost people do not realise when their posture is wrong

### ØTechnology can help by detecting posture automatically

### ØOur project monitors posture and gives feedback using vibration alerts

# LITERATURE SURVEY

SL. N O | Paper Title | Author Names | Proposed Work | Publishe d Year
1 | UWB-PostureGuard: A Privacy-Preserving RF Sensing System for Continuous Ergonomic Sitting Posture Monitoring | Haotang Li, Zhenyu Qi, Sen He, Kebin Peng, Sheng Tan, Yili Ren, Tomas Cerny, Jiyue Zhao, Zi Wang | Proposes a contactless, UWB (ultra-wideband) RF sensing system that continuously monitors sitting posture with 99.11% accuracy. It preserves user privacy (no camera/wearables) and is robust to variations like clothing, furniture, and environment. | 2025
2 | Sitting Posture Recognition and Feedback: A Literature Review | Christian Krauter, Katrin Angerbauer, Aimée Sousa Calepso, Alexander Achberger, Sven Mayer, Michael Sedlmair | Comprehensive literature review (N=223) across engineering, electronics, medical sciences; highlights use of pressure-sensing hardware and visual feedback; discusses factors such as environment, cost, privacy, portability, accuracy, user capability and long-term effects | 2024
3 | Sensor-Based Wearable Systems for Monitoring Human Motion and Posture: A Review

Xinxin Huang, Yunan Xue,
Shuyun Ren, Fei Wang

Systematic review of wearable posture-monitoring systems; analyses sensor types (IMU, flex, pressure), placement strategies, system design aspects, and emphasises future needs like accuracy, data security, comfort, and durability.

2024

09/10/2026 | Body Posture Monitor For Desk Workers | 6

09/10/2026 | Body Posture Monitor For Desk Workers | 7
SL.N O | PAPER TITLE | AUTHOR NAMES | PROPOSED WORK | PUBLISHE D YEAR
4. A Smart System for Sitting | Posture Detection Based on Force Sensors and Mobile Application | Slavomir Matuska, Martin Paralic, Robert Hudec | Presents a smart chair with six flexible force sensors connected to an Arduino-based IoT node; detects incorrect sitting positions and sends feedback to a mobile app, with posture data stored in a private cloud and visualized | 2022
5. | Human Posture Detection Method Based on Wearable Devices | Xiaoou Li Yangang Li Yuanming Wu Jiahui Xu Zhitao Xiao | Proposes a multimodal wearable posture detection method using upper-limb sEMG, lower-limb inertial and plantar pressure sensors; features are extracted via wavelet transforms and classified using optimized | 2021

via mobile UI.

SVM with ~90% accuracy.

# LITERATURE SURVEY

# OBJECTIVES

ØTo design a posture monitoring system for desk workers. ØTo measure body angle using the MPU6050 sensor.
ØTo process sensor data using ESP32.
ØTo detect wrong posture accurately.
ØTo alert the user using vibration feedback.
ØTo avoid false alerts during temporary movements.
ØTo implement a 40-second delay before triggering vibration. ØTo improve health and working comfort.

# COMPONENTS

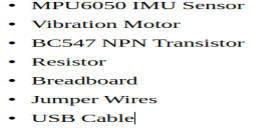
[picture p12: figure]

# BLOCK DIAGRAM

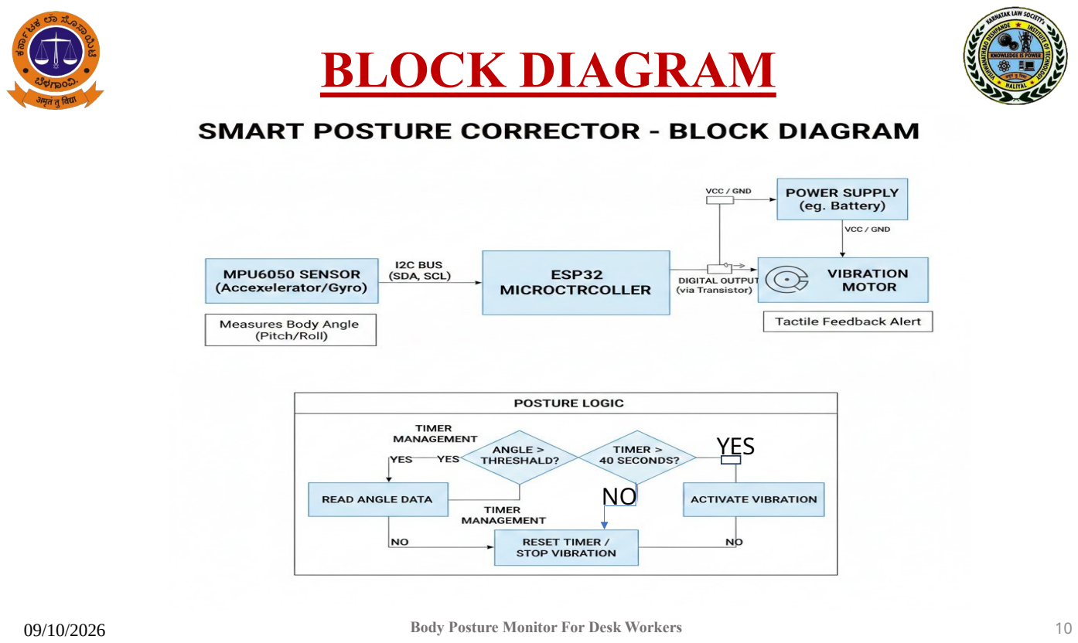
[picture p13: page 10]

YES
NO

# CIRCUIT DIAGRAM

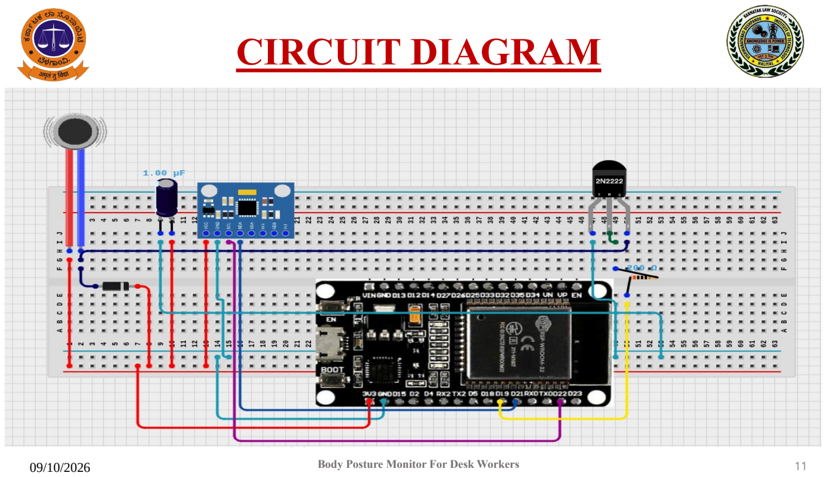
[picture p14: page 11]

Fig.1 : Block Diagram of Body Posture Monitor For Desk Workers

# WORKING

ØThe MPU6050 sensor continuously measures body angle. ØESP32 reads angle data from MPU6050.
ØThe angle is compared with a preset normal posture value. ØIf posture is correct → System continues monitoring.
ØIf posture is wrong, → Timer starts counting.
ØIf posture is corrected within 40 seconds, → Timer resets. ØIf posture remains wrong for more than 40 seconds →
- Vibration motor is activated.
ØVibration alert reminds user to correct posture.
ØOnce posture is corrected → Vibration stops.

# OUTCOMES

Ø The system accurately detects the user's body posture.
Ø It continuously monitors posture in real time.
Ø The vibration alert effectively notifies the user when posture is incorrect.
Ø False alerts are reduced by using a delay timer mechanism.
Ø The system helps increase awareness about correct posture habits.
Ø Users receive a physical reminder through vibration to correct their posture. Ø The system is portable and suitable for daily use.
Ø The project helps in reducing long-term back and neck problems.

# ADVANTAGES

Ø The system helps users maintain correct sitting posture.

Ø It provides real-time feedback through vibration alerts.

Ø The delay timer prevents unnecessary or false alerts.

Ø The device is simple and easy to operate.

Ø The system is affordable and cost-effective.

Ø People of all age groups can use it.

Ø The device improves long-term spinal health.

# APPLICATIONS

ØThe system can be used in corporate offices to promote healthy working posture.

ØIt is suitable for educational institutions to improve students’ and teachers sitting habits.

ØThe device is useful in call centers and BPO industries.

ØIt can be implemented in co-working spaces.

ØIt is useful for people with back or neck discomfort.

ØThe system can be used in rehabilitation and physiotherapy centers.

ØIt is suitable for training programs focused on workplace safety.

ØThe device can be used to monitor posture during long reading or writing sessions.

# REFERENCES

Ø Haotang Li, Zhenyu Qi, Sen He, Kebin Peng, Sheng Tan, Yili Ren, Tomas Cerny, Jiyue Zhao, Zi Wang,

“UWB-PostureGuard: A Privacy-Preserving RF Sensing System for Continuous Ergonomic Sitting Posture Monitoring,” 2025.

Ø Christian Krauter, Katrin Angerbauer, Aimée Sousa Calepso, Alexander Achberger, Sven Mayer,

Michael Sedlmair, “ Sitting posture Recognition and Feedback: A Literature Review.”:2024.

Ø Xiaoou Li, Yangang Li, Yuanming Wu, Jiahui Xu, Zhitao Xiao,” Human Posture Detection Method Based

on Wearable Devices”:2021

Ø Slavomir Matuska, Martin Paralič, Robert Hudec, “A Smart System for Sitting Posture Detection Based on

Force Sensors and Mobile Application”, 2022

# ACKNOWLEDGEMENT

Ø We would like to thank our Honourable Principal, Dr V. A. Kulkarni sir for their

fabulous support.

Ø We would like to thank Dr Nagaraj Bhat sir, for their fabulous support.

ØWe would like to express our special thanks to our guide, Dr Nagaraj Bhat for their

guidance in choosing this project, “Design and Implementation of Body Posture Monitor For Desk Workers”.

# THANK YOU

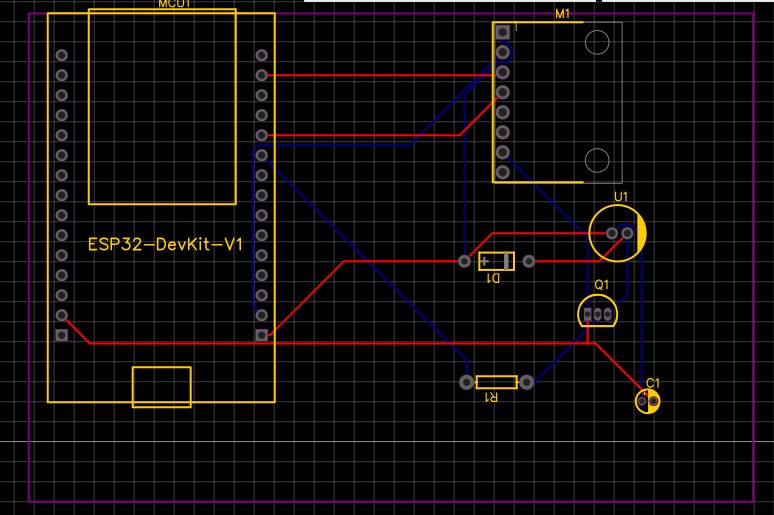
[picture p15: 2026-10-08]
hardware/pcb/Final_PCB/PCB_image1.jpeg

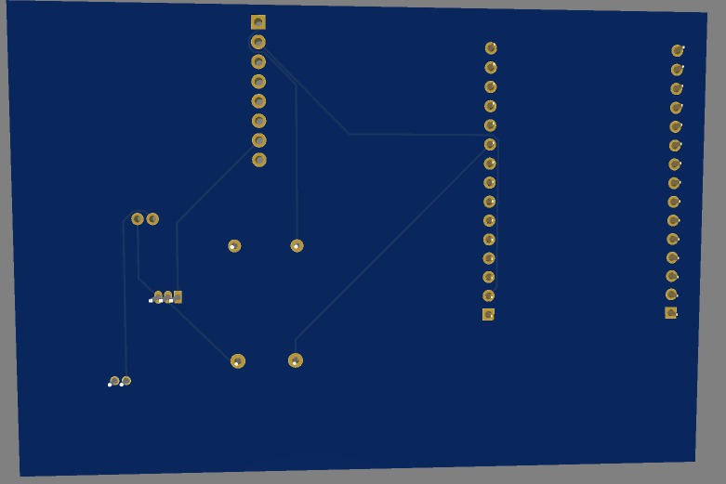
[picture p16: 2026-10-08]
hardware/pcb/Final_PCB/PCB_image3.jpeg

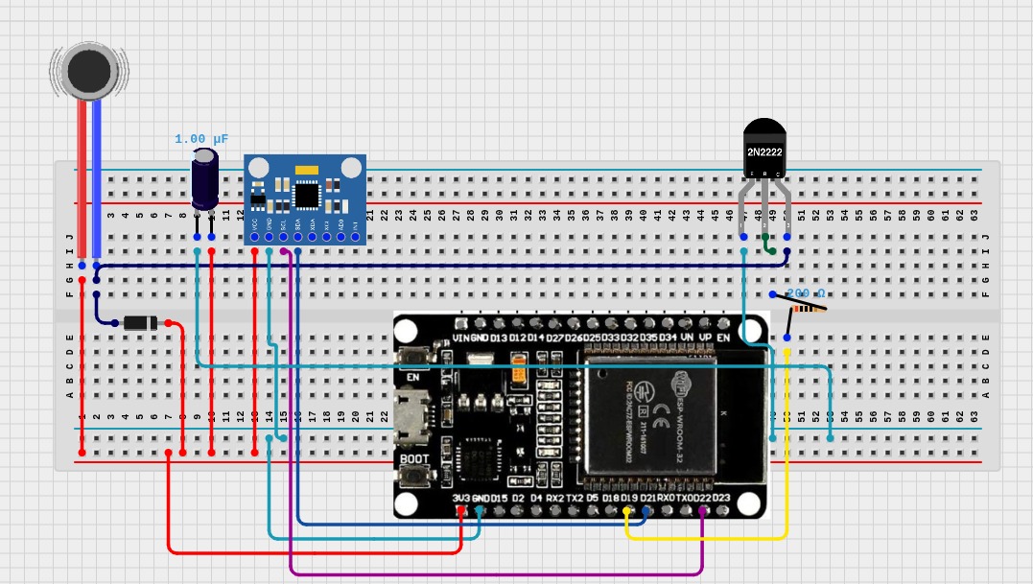
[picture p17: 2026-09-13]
hardware/circuit_diagram/circuit_diagram.jpeg

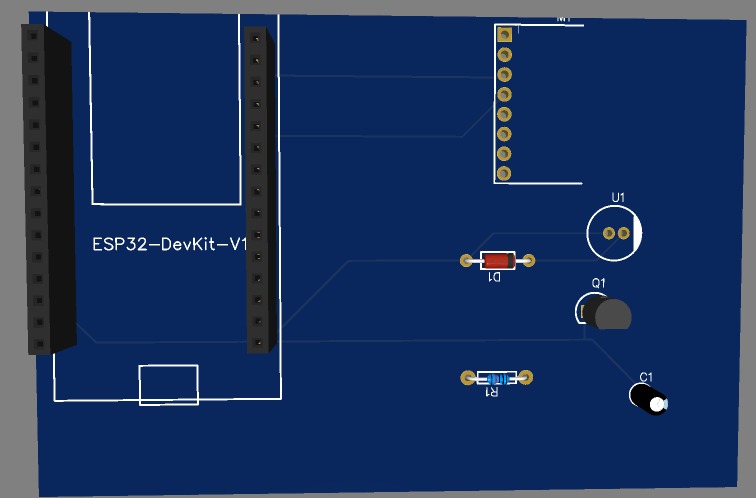
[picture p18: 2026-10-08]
hardware/pcb/Final_PCB/PCB_image2.jpeg

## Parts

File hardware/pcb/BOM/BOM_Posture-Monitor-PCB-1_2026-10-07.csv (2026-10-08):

ID | Name | Designator | Footprint | Quantity | Manufacturer Part | Manufacturer | Supplier | Supplier Part | Price | Pins | 3DModel | Contributor | JLCPCB Part Class | link
1 | 100u | C1 | CAP-D3.0×F1.5 | 1 |  |  |  |  |  | 2 | CAP-D3.0×H5.0×F1.5 | LCEDA_Lib
2 | 1N4148 | D1 | DO-35_BD2.0-L4.2-P8.20-D0.5-RD | 1 | 1N4148 | STMicroelectronics | LCSC | C13769 |  | 2 | DO-35_D1.9-L3.9-P8.2 | LCSC |  | https://item.szlcsc.com/86229.html
3 | MPU6050 | M1 | MPU6050 | 1 |  |  |  |  |  | 8 |  | Hassan80046
4 | ESP32-DevKit-V1 | MCU1 | ESP32-DEVKIT-V1-FOOTPRINT | 1 | ESP32-DevKit-V1 | Espressif | Aliexpress |  |  | 30 | PinSocket_ESP32DevKitV1_2x15_P2.54mm_Vertical | pvatolin
5 | 2N2222 | Q1 | TO-92-3_L4.9-W3.7-P1.27-L | 1 | 2N2222A | ST(先科) | LCSC | C118536 | 0.04 | 3 | TO-92-3_L4.9-W3.7-P1.27-L | LCSC | Extended Part | https://atta.szlcsc.com/upload/public/pdf/source/20180629/C233232_99576441F8ED8E9074FB1575A6BE3592.PDF
6 | 1k | R1 | R_AXIAL-0.3 | 1 |  |  |  |  |  | 2 | R_AXIAL-0.3 | LCEDA_Lib
7 | VC0720B001F | U1 | DIP_VC0720B001F | 1 | VC0720B001F | Vybronics | LCSC | C17184937 |  | 2 |  | lcsc | Extended Part | https://www.vybronics.com/coin-vibration-motors/with-brushes/v-c0720b001f

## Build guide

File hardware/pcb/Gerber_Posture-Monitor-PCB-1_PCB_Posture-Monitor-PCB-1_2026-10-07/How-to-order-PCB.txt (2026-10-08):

How to Order PCB

Please refer to:
https://docs.easyeda.com/en/PCB/Order-PCB

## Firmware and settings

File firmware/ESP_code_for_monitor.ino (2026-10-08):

#include <WiFi.h>
#include <AsyncTCP.h>
#include <ESPAsyncWebServer.h>
#include <Wire.h>
#include <ArduinoJson.h>
#include "FS.h"
#include "LittleFS.h"

// ========= WiFi credentials =========
const char* ssid     = "YOUR_HOTSPOT_NAME";
const char* password = "YOUR_PASSAWORD";

// ========= Web server =========
AsyncWebServer server(80);

// ========= MPU6050 =========
const int MPU_ADDR = 0x68;
int16_t AcX, AcY, AcZ;
float pitch;

// ========= Posture logic =========
float refPitch = 0;
bool calibrated = false;
unsigned long calibStartTime = 0;
const unsigned long CALIB_DURATION = 5000;   // 5s for good posture at start

float deviation = 0;
const float PITCH_TOLERANCE = 15.0;          // allowed deviation in degrees

// 🔴 CHANGED: 30s -> 10s
const unsigned long BAD_DELAY = 40000;       // 10s continuous bad posture

bool isCurrentlyBad = false;
bool postureBadConfirmed = false;
unsigned long badStartTime = 0;
unsigned long badSeconds = 0;

// ========= VIBRATOR (transistor driver) =========
// 🔧 CHANGE THIS to the GPIO you actually use (e.g. 4 or 14)
const int VIBRATOR_PIN = 19;   // example: GPIO4 (D4)

// ========= MPU helper =========
void readMPU() {
  Wire.beginTransmission(MPU_ADDR);
  Wire.write(0x3B);
  Wire.endTransmission(false);
  Wire.requestFrom(MPU_ADDR, 6, true);

  AcX = Wire.read() << 8 | Wire.read();
  AcY = Wire.read() << 8 | Wire.read();
  AcZ = Wire.read() << 8 | Wire.read();

  float Ax = AcX / 16384.0;
  float Ay = AcY / 16384.0;
  float Az = AcZ / 16384.0;

  // pitch from accelerometer (same as your original code)
  pitch = atan2(Ay, sqrt(Ax * Ax + Az * Az)) * 180.0 / PI;  // degrees
}

// ========= HTTP handlers =========
void handlePosture(AsyncWebServerRequest *request) {
  // decide status string
  const char* statusStr;
  if (postureBadConfirmed)      statusStr = "BAD";
  else if (isCurrentlyBad)      statusStr = "POTENTIALLY_BAD";
  else                          statusStr = "GOOD";

  StaticJsonDocument<256> doc;
  doc["pitch"]      = pitch;
  doc["refPitch"]   = refPitch;
  doc["deviation"]  = deviation;
  doc["badSeconds"] = badSeconds;      // always a number
  doc["status"]     = statusStr;

  String json;
  serializeJson(doc, json);
  request->send(200, "application/json", json);
}

// ========= Setup =========
void setup() {
  Serial.begin(115200);
  delay(1000);

  // I2C + MPU6050
  Wire.begin(21, 22);  // SDA, SCL on ESP32
  Wire.beginTransmission(MPU_ADDR);
  Wire.write(0x6B);
  Wire.write(0);   // wake up MPU6050
  Wire.endTransmission();

  // Vibrator pin setup
  pinMode(VIBRATOR_PIN, OUTPUT);
  digitalWrite(VIBRATOR_PIN, LOW);  // make sure it's OFF at start

  // LittleFS
  if (!LittleFS.begin(true)) {   // true = format if mount fails
    Serial.println("LittleFS Mount Failed");
    while (true) delay(1000);
  }
  Serial.println("LittleFS mounted successfully");

  // WiFi
  WiFi.begin(ssid, password);
  Serial.print("Connecting to WiFi");
  while (WiFi.status() != WL_CONNECTED) {
    Serial.print(".");
    delay(500);
  }
  Serial.println("\nWiFi connected");
  Serial.print("ESP32 IP: ");
  Serial.println(WiFi.localIP());

  // Web routes
  server.serveStatic("/", LittleFS, "/").setDefaultFile("index.html");
  server.on("/posture", HTTP_GET, handlePosture);

  server.begin();
  Serial.println("Async WebServer started");

  // Start calibration
  calibStartTime = millis();
  Serial.println("Sit in GOOD posture for 5 seconds...");
}

// ========= Calibration loop =========
void loopCalibration() {
  static float sum = 0;
  static int count = 0;

  readMPU();

  if (millis() - calibStartTime < CALIB_DURATION) {
    sum += pitch;
    count++;
    Serial.print("Calibrating... pitch=");
    Serial.println(pitch);
  } else if (!calibrated && count > 0) {
    refPitch = sum / count;
    calibrated = true;
    Serial.println("\nCalibration DONE!");
    Serial.print("refPitch = ");
    Serial.println(refPitch);
    Serial.println("---------------------------");
  }
}

// ========= Posture loop =========
void loopPosture() {
  readMPU();
  unsigned long now = millis();

  deviation = pitch - refPitch;
  float absDev = fabs(deviation);
  bool currentlyBad = (absDev > PITCH_TOLERANCE);

  if (currentlyBad) {
    if (!isCurrentlyBad) {
      isCurrentlyBad = true;
      badStartTime = now;
      postureBadConfirmed = false;
    } else if (!postureBadConfirmed && (now - badStartTime >= BAD_DELAY)) {
      postureBadConfirmed = true;
    }
  } else {
    isCurrentlyBad = false;
    postureBadConfirmed = false;
  }

  if (isCurrentlyBad) badSeconds = (now - badStartTime) / 1000;
  else                badSeconds = 0;

  // ========= Vibrator control =========
  // Vibrate ONCE for 1–3 seconds when BAD posture is confirmed (after 10s)
  static bool buzzedOnce = false;
  const unsigned long BUZZ_DURATION = 3000; // 2s vibration (change 1000–3000 if you want)
  static unsigned long buzzStartTime = 0;

  if (postureBadConfirmed) {
    if (!buzzedOnce) {
      buzzedOnce = true;
      buzzStartTime = now;
      digitalWrite(VIBRATOR_PIN, HIGH); // start buzzing
      Serial.println("Buzz started");
    }

    // stop buzzing after BUZZ_DURATION
    if (buzzedOnce && (now - buzzStartTime >= BUZZ_DURATION)) {
      digitalWrite(VIBRATOR_PIN, LOW);
    }

  } else {
    // Reset when posture returns to GOOD / short deviation
    buzzedOnce = false;
    digitalWrite(VIBRATOR_PIN, LOW);
  }

  // Debug
  Serial.print("Pitch=");
  Serial.print(pitch);
  Serial.print(" ref=");
  Serial.print(refPitch);
  Serial.print(" dev=");
  Serial.print(deviation);
  Serial.print(" absDev=");
  Serial.print(absDev);
  Serial.print(" status=");
  if (postureBadConfirmed)      Serial.println("BAD");
  else if (isCurrentlyBad)      Serial.println("POTENTIALLY_BAD");
  else                          Serial.println("GOOD");
}

// ========= Main loop =========
void loop() {
  if (!calibrated) {
    loopCalibration();
  } else {
    loopPosture();
  }

  delay(200);  // ~5 Hz updates
}

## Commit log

2026-09-13 Add Body Posture Monitor project
    Corrected spacing in the README for MPU6050 and ESP32 descriptions.
2026-10-08 add hardware to project
    [BOM_Posture-Monitor-PCB-1_2026-10-07.csv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]
